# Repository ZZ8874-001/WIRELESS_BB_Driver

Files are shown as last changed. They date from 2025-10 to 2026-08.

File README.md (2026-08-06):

# WireLess BB Driver

同步 Buck 降压变换器固件，STM32F334C8 + 无线模块，非反馈线性控制 (NFB)。

---

## 目录

1. [构建环境](#1-构建环境)
2. [系统架构](#2-系统架构)
3. [外设配置](#3-外设配置)
4. [HRTIM 详细规格](#4-hrtim-详细规格)
5. [控制算法](#5-控制算法)
6. [代码文件结构](#6-代码文件结构)
7. [状态机](#7-状态机)
8. [变量定义与赋值关系](#8-变量定义与赋值关系)
9. [检测系统](#9-检测系统)
10. [ADC 数据流](#10-adc-数据流)
11. [串口通信](#11-串口通信)

---

## 1. 构建环境

```bash
make clean && make -j    # 完整重建
make -j                  # 增量构建
```

| 项 | 值 |
|----|-----|
| MCU | STM32F334C8 |
| 内核 | Cortex-M4 + FPU (fpv4-sp-d16) |
| 编译器 | arm-none-eabi-gcc |
| 优化 | `-O2` |
| 调试 | `-g -gdwarf-2` |
| 输出 | `build/WireLess_BB_Driver.elf/.hex/.bin` |
| 工具链 | STM32CubeMX 生成 HAL + 手动覆盖 |

---

## 2. 系统架构

```
┌────────────────────────────────────────────────────┐
│                    main.c                           │
│  SystemClock_Config() → HSE 8MHz ×6 = 48MHz PLL  │
│  HRTIM1 = PLLCLK (48MHz ×2 = 96MHz)               │
│  APB1 = 24MHz, APB2 = 48MHz                       │
│  ADC12 clock = PLL/2 = 24MHz                      │
│                                                     │
│  HAL_TIM_PeriodElapsedCallback (TIM2 @10kHz)       │
│    ├── Bsp_ADC_ProcessSample()  // 每秒10k次       │
│    ├── Buck_Boost_Task()        // 每秒10k次       │
│    └── Detect_Task()            // 每10tick=1kHz   │
└────────────────────────────────────────────────────┘
```

- **裸机**，无 RTOS
- 所有实时逻辑由 `HAL_TIM_PeriodElapsedCallback` (TIM2) 以 **10 kHz** 驱动
- ADC 由 HRTIM Timer C 在 **~100 kHz** 触发，DMA 循环搬运
- USART3 通过 **DMA + IDLE 中断** 异步接收无线数据

---

## 3. 外设配置

### 3.1 时钟树 (`Core/Src/main.c:143`)

| 时钟 | 来源 | 频率 |
|---|---|---|
| HSE | 外部晶振 | 8 MHz |
| PLL | HSE ×6 | 48 MHz |
| SYSCLK | PLL | 48 MHz |
| HCLK | SYSCLK/1 | 48 MHz |
| APB1 (PCLK1) | HCLK/2 | 24 MHz |
| APB2 (PCLK2) | HCLK/1 | 48 MHz |
| HRTIM1CLK | PLLCLK (×2) | 96 MHz |
| ADC12CLK | PLLCLK/2 | 24 MHz |

### 3.2 GPIO 映射

| 引脚 | 功能 | 方向 | AF | 文件位置 |
|---|---|---|-----|---|
| PA0 | ADC1_IN1 (Vout 采样) | Analog | — | `Core/Src/adc.c:188` |
| PA1 | ADC1_IN2 (Vin 采样) | Analog | — | `Core/Src/adc.c:188` |
| PA4 | ADC2_IN1 (Iout+) | Analog | — | `Core/Src/adc.c:229` |
| PA5 | ADC2_IN2 (Iout-) | Analog | — | `Core/Src/adc.c:229` |
| PA6 | VCC_Indicator | Output PP | — | `Core/Src/gpio.c:56` |
| PA7 | BBEN_Indicator | Output PP | — | `Core/Src/gpio.c:62` |
| PA8 | HRTIM1_CHA1 (ADC触发) | AF PP | AF13 | `Core/Src/hrtim.c:248` |
| PA10 | HRTIM1_CHB1 (Buck 下管) | AF PP | AF13 | `Core/Src/hrtim.c:248` |
| PA11 | HRTIM1_CHB2 (Buck 上管) | AF PP | AF13 | `Core/Src/hrtim.c:248` |
| PB10 | USART3_TX | AF PP | AF7 | `Core/Src/usart.c:80` |
| PB11 | USART3_RX | AF PP | AF7 | `Core/Src/usart.c:80` |

### 3.3 ADC 配置

文件 `Core/Src/adc.c:33` `MX_ADC1_Init()`, `Core/Src/adc.c:117` `MX_ADC2_Init()`

| 参数 | ADC1 | ADC2 |
|---|---|---|
| Clock | Async DIV1 (24 MHz) | Async DIV1 (24 MHz) |
| Resolution | 12 bit | 12 bit |
| Scan | Enabled | Disabled |
| Continuous | Disabled | Disabled |
| Trigger Edge | Rising | Rising |
| **Trigger Src** | `ADC_EXTERNALTRIGCONVHRTIM_TRG1` | `ADC_EXTERNALTRIGCONVHRTIM_TRG3` |
| NbrOfConversion | 2 (CH1=Rank1, CH2=Rank2) | 1 (CH1=Rank1, differential) |
| DMA Requests | Continuous | Continuous |
| Sampling Time | 7.5 cycles | 7.5 cycles |

**DMA 配置** (由 `HAL_ADC_MspInit` 在 `Core/Src/adc.c:171`):

| 参数 | DMA1_Channel1 (ADC1) | DMA1_Channel4 (ADC2) |
|---|---|---|
| Direction | Peripheral → Memory | Peripheral → Memory |
| PeriphInc | Disabled | Disabled |
| MemInc | Enabled | Enabled |
| Data Align | Half-word | Half-word |
| **Mode** | **Circular** | **Circular** |
| Priority | Low | Low |

**BSP 层重配置** (`Bsp/bsp_adc.c:49` `Bsp_ADC_Init()`):

DMA 循环缓冲区长度由头文件定义：
```c
// bsp_adc.h:18-20
#define ADC_VOUT_BUF_SIZE  10
#define ADC_VIN_BUF_SIZE   10
#define ADC_CURR_BUF_SIZE  10

// bsp_adc.h:23-24
#define ADC1_DMA_BUF_SIZE  (ADC_VOUT_BUF_SIZE * 2)  // = 20
#define ADC2_DMA_BUF_SIZE  (ADC_CURR_BUF_SIZE)       // = 10
```

- `ADC1_DMA_Buf[20]`: 交织布局 `[Vout0 ,Vin0 , Vout1, Vin1, ..., Vout9, Vin9]`
- `ADC2_DMA_Buf[10]`: `[I0, I1, ..., I9]`
- DMA 半传输/传输完成中断被**禁用** (`bsp_adc.c:69-70`)
- ADC1 AWD2 模拟看门狗监控 CH2 (Vin) (`bsp_adc.c:73-74`)

### 3.4 USART3 配置

文件 `Core/Src/usart.c:33` `MX_USART3_UART_Init()`

| 参数 | 值 |
|---|-----|
| Baud Rate | 115200 |
| Word Length | 8 bit |
| Stop Bits | 1 |
| Parity | None |
| Mode | TX+RX |
| Hardware Flow | None |
| **OverSampling** | **8×** (`UART_OVERSAMPLING_8`) |
| ISR Priority | 0 (最高) |

**BSP 层重置** (`Bsp/bsp_uart.c:12` `Bsp_UART_Init()`):

直接寄存器写覆盖 HAL 配置：
1. `DMA1_Channel3->CCR = 0` — 清零 RX DMA
2. `USART3->CR1 = 0` — 清零 USART
3. 重新配置 DMA: `CCR |= DMA_CCR_MINC`, CNDTR=255, CPAR=&USART3->RDR, CMAR=Rx_data
4. `USART3->CR3 |= USART_CR3_DMAR | USART_CR3_DMAT` — 启用 DMA 收发
5. `USART3->CR1 |= IDLEIE | TE | RE | UE | OVER8` — **注意**：`OVER8` **必须保留**，否则波特率偏差 2×

**ISR**: `Core/Src/stm32f3xx_it.c:296` `USART3_IRQHandler` → `USER_USART_InterruptCallback(&huart3)` (`Bsp/bsp_uart.c:38`)

### 3.5 TIM2 配置

TIM2 产生 10 kHz 主循环中断。由 CubeMX 生成 `Core/Src/tim.c`。

---

## 4. HRTIM 详细规格

### 4.1 时钟与周期

| 参数 | 值 | 来源 |
|---|-----|---|
| 时钟源 | PLLCLK (96 MHz) | `Core/Src/main.c:179` `RCC_HRTIM1CLK_PLLCLK` |
| Period (Master) | 23040 | `Core/Inc/main.h:63` `Hrtim_Period` |
| 预分频基准 | `HRTIM_PRESCALERRATIO_MUL2` (TimerA) | `Core/Src/hrtim.c:75` |
| DLL 校准 | 14 周期 | `Core/Src/hrtim.c:54` |

### 4.2 Timer 配置

| Timer | 功能 | Prescaler | 周期 (分辨率) | Reset Trigger | Reset Update | 文件位置 |
|---|---|---|---|---|---|---|
| **A**  | 输出 TA1 (ADC 触发基准) | MUL2 | 96M×2/23040 ≈ 8.33 kHz | CMP2 | Enabled | `hrtim.c:73-105` |
| **B**  | Buck PWM (TB1/TB2) | MUL32 | 96M×32/23040 ≈ 133.3 kHz | Update \| Other1_CMP2 | Disabled | `hrtim.c:106-113` |
| **C**  | ADC 触发 | MUL16 | 96M×16/23040 ≈ 66.7 kHz | Other1_CMP2 | Enabled | `hrtim.c:114-121` |

### 4.3 HRTIM 寄存器地址映射

基地址: `HRTIM1 = 0x40017400`

#### Master 寄存器

| 寄存器 | 偏移 | 位宽 | 访问 | 描述 |
|---|---|---|---|---|
| `MCR` | 0x00 | 32 | rw | Master 控制寄存器 |
| `MISR` | 0x04 | 32 | r | Master 中断状态 |
| `MICR` | 0x08 | 32 | w | Master 中断清除 |
| `MDIER` | 0x0C | 32 | rw | Master DMA/中断使能 |
| `MCNTR` | 0x10 | 32 | r | Master 计数器 (只读) |
| `MPER` | 0x14 | 32 | rw | Master 周期 |
| `MREP` | 0x18 | 32 | rw | Master 重复计数 |
| `MCMP1R` | 0x1C | 32 | rw | Master 比较 1 |
| `MCMP2R` | 0x24 | 32 | rw | Master 比较 2 |
| `MCMP3R` | 0x28 | 32 | rw | Master 比较 3 |
| `MCMP4R` | 0x2C | 32 | rw | Master 比较 4 |

#### Timer A 寄存器 (sTimerxRegs[0], 偏移 0x80)

| 寄存器 | 偏移 | 描述 |
|---|---|---|
| `TIMxCR` | 0x80 | Timer A 控制 |
| `TIMxISR` | 0x84 | Timer A 中断状态 |
| `TIMxICR` | 0x88 | Timer A 中断清除 |
| `TIMxDIER` | 0x8C | Timer A DMA/中断使能 |
| `CNTxR` | 0x90 | Timer A 计数器 |
| `PERxR` | 0x94 | Timer A 周期 |
| `REPxR` | 0x98 | Timer A 重复 |
| `CMP1xR` | 0x9C | Timer A 比较 1 |
| `CMP2xR` | 0xA4 | Timer A 比较 2 |
| `CMP3xR` | 0xA8 | Timer A 比较 3 |
| `CMP4xR` | 0xAC | Timer A 比较 4 |

#### Timer B 寄存器 (sTimerxRegs[1], 偏移 0x100)

| 寄存器 | 偏移 | 描述 |
|---|---|---|
| `CMP1xR` | 0x11C | Timer B 比较 1 (Buck 下管) |
| `CMP2xR` | 0x124 | Timer B 比较 2 (Buck 上管) |

#### Timer C 寄存器 (sTimerxRegs[2], 偏移 0x180)

| 寄存器 | 偏移 | 描述 |
|---|---|---|
| `CMP2xR` | 0x1A4 | Timer C 比较 2 → ADC Trigger 1 |
| `CMP3xR` | 0x1A8 | Timer C 比较 3 → ADC Trigger 3 |

#### 公共控制寄存器

| 寄存器 | 偏移 | 访问 | 描述 |
|---|---|---|---|
| `OENR` | 0x380 | w | 输出使能 Set (`bb_control.c:108,387`) |
| `ODISR` | 0x384 | w | 输出禁能 Set (`bb_control.c:109,391`) |

### 4.4 比较值与触发配置

| 比较器 | 值 | 用途 | 文件 |
|---|-----|---|---|
| Timer A CMP2 | `Hrtim_Period` (=23040) | Timer A 自复位 + Timer B/C 复位基准 | `hrtim.c:122` |
| Timer A CMP3 | `Hrtim_Period/32` (=720) | TA1 输出 Set | `hrtim.c:137` |
| Timer A CMP4 | `Hrtim_Period/32+96` (=816) | TA1 输出 Reset | `hrtim.c:143` |
| Timer B CMP1 | `(Period-Period/2)/2*0.95` | TB1 输出 Set (下管) | `hrtim.c:176` |
| Timer B CMP2 | `(Period+Period/2)/2*0.95` | TB1 输出 Reset / TB2 Set (上管,运行时改写) | `hrtim.c:130` |
| Timer C CMP2 | `Hrtim_Period/4` (=5760) | ADC Trigger 1 | `hrtim.c:133` |
| Timer C CMP3 | `Hrtim_Period/4+96` (=5856) | ADC Trigger 3 | `hrtim.c:204` |

### 4.5 输出配置

| 输出 | 编号 | Set Src | Reset Src | Idle | 实际使用 |
|---|---|---|---|---|---|
| TA1 | 0 | TIMCMP3 | TIMCMP4 | Inactive | ADC 触发基准 |
| TB1 | 1 | TIMCMP1 | TIMCMP2 | Inactive | Buck 下管 (同步整流) |
| TB2 | 2 | NONE | NONE | Inactive | Buck 上管 (互补, 由死区生成) |

死区时间 (`hrtim.c:181-193`):
- 上升沿 (Rising): +10 (Prescaler DIV1)
- 下降沿 (Falling): +10

### 4.6 ADC 触发连接

| ADC 通道 | HRTIM 触发 | 源事件 | 更新源 | 文件 |
|---|---|---|---|---|
| ADC1 | `HRTIM_ADCTRIGGER_1` | `TIMERC_CMP2` | `UPDATE_TIMER_C` | `hrtim.c:62-66` |
| ADC2 | `HRTIM_ADCTRIGGER_3` | `TIMERC_CMP3` | `UPDATE_TIMER_C` | `hrtim.c:68-71` |

### 4.7 代码中对 HRTIM 寄存器的直接写入

| 操作 | 位置 | 说明 |
|---|---|---|
| `sCommonRegs.OENR = BUCK_OUTPUT_MASK` | `bb_control.c:387` | 使能 TB1/TB2 输出 |
| `sCommonRegs.ODISR = BUCK_OUTPUT_MASK` | `bb_control.c:391` | 禁能 TB1/TB2 输出 |
| `sCommonRegs.OENR = HRTIM_OUTPUT_TA1` | `bb_control.c:108` | 使能 TA1 (ADC 触发) |
| `sCommonRegs.ODISR = BUCK_OUTPUT_MASK` | `bb_control.c:109` | 禁能 TB1/TB2 (初始化) |
| `sMasterRegs.MCMP1R = Hrtim_Period` | `main.c:110` | Master 比较 1 |
| `sMasterRegs.MCMP2R = 0` | `main.c:111` | Master 比较 2 |
| `sTimerxRegs[B].CMP1xR = ...` | `bb_control.c:357,362` | Buck 下管关断点 |
| `sTimerxRegs[B].CMP2xR = ...` | `bb_control.c:358,363` | Buck 上管关断点 |
| `sTimerxRegs[B].CMP1xR = Hrtim_Period` | `bb_control.c:357` | 故障态: 下管永开 |
| `sTimerxRegs[B].CMP2xR = 0` | `bb_control.c:358` | 故障态: 上管永关 |

### 4.8 HRTIM 输出掩码位定义

```c
// stm32f3xx_hal_hrtim.h
HRTIM_OUTPUT_TA1 = (0x00000002U)  // bit 1
HRTIM_OUTPUT_TB1 = (0x00000008U)  // bit 3
HRTIM_OUTPUT_TB2 = (0x00000010U)  // bit 4
BUCK_OUTPUT_MASK  = HRTIM_OUTPUT_TB1 | HRTIM_OUTPUT_TB2  // = 0x18
```

---

## 5. 控制算法

### 5.1 NFB (Non-Linear Feedback) 非反馈控制

`bb_control.c:367` `NFB_Calculate()` (10 kHz 调用):

```
① 电压增益计算
  voltage_gain_measure_ = constrain(Vout/Vin, 0.05, 0.95)   // 实测增益
  voltage_gain_ref_     = constrain(Vref/Vin,  0.05, 0.95)   // 目标增益

② Gain_Limit = max(0.95 - gain_ref, gain_ref - 0.05)

③ 电压环
  err_volt = (gain_measure - gain_ref) / Gain_Limit
  voltage_gain_NFB_ = gain_ref + Kp_Volt × sin(err_volt × π/2)
  约束到 [0.05, 0.95]

④ 电流环
  Curr_Normalized = constrain((Iout - Iref) / Iref, -0.95, 0.95)
  current_gain_NFB_ = volt_gain_NFB + Kp_Curr × sin(Curr_Normalized × π/2)
  约束到 [0.05, 0.95]

⑤ 电流增益滤波
  current_gain_NFB_f_ = First_Order_Filter(current_gain_NFB_)  // fc=50Hz
```

### 5.2 CV/CC 切换

`bb_control.c:273` 在 `Data_Handle()` 中:

```
if Iout > Iref + 0.05  →  is_CC = 1  →  Kp_Curr_NFB ×1.001  (逐步收紧)
if Iout < Iref         →  is_CC = 0  →  Kp_Curr_NFB ×0.95   (逐步放松)

final_gain = 
  if cur_gain_f > volt_gain × 1.05 && 超时过期 → volt_gain (电压环占优)
  if cur_gain_f < volt_gain                    → cur_gain_f (电流环占优, 且钩住 TOE)
  else                                         → (volt_gain + cur_gain_f) / 2 (平滑过渡)
```

### 5.3 占空比计算

`bb_control.c:316` `Duty_Calculate()`:

| 状态 | 占空比 |
|---|---|
| Buck | `constrain(final_gain, 0.05, 0.95)` |
| VoltIpt_Error | `0` |
| Soft_Start | `constrain(final_gain × (t - t0)/200ms + 0.026, 0.05, 0.95)` |

### 5.4 PWM 输出

`bb_control.c:343` `MOS_PWM_Set()` — 直接写 HRTIM Timer B 的比较寄存器:

- 上管 (TB2): `CMP2xR = (1 + (1-duty)) / 2 × Hrtim_Period`
- 下管 (TB1): `CMP1xR = (1 - (1-duty)) / 2 × Hrtim_Period`
- 故障态: 上管 CMP2=0 (永关), 下管 CMP1=Period (永开)

### 5.5 灌电流/过压保护 (OVP)

`bb_control.c:395` `Is_Buck_OutputVoltage_Allowed()`:

```
滞回比较器:
  触发: Vout > Vin × 1.40  →  active = true  →  输出禁止
  释放: Vout ≤ Vin × 0.85  →  active = false →  输出使能
```

`bb_control.c:383` `Update_Buck_Output_Enable()`:
- `Wireless_EN_flag && OVP 允许` → `OENR = BUCK_OUTPUT_MASK`
- 否则 → `ODISR = BUCK_OUTPUT_MASK`

---

## 6. 代码文件结构

```
BB_Driver/
├── Core/                          # CubeMX 生成
│   ├── Inc/
│   │   ├── main.h                 # 全局宏: 占空比限幅, Pin 定义
│   │   ├── adc.h / dma.h / gpio.h / hrtim.h / tim.h / usart.h
│   │   └── stm32f3xx_it.h
│   └── Src/
│       ├── main.c                 # 入口, 时钟, TIM2 回调
│       ├── adc.c                  # MX_ADC1/2_Init, HAL_ADC_MspInit
│       ├── dma.c                  # MX_DMA_Init
│       ├── gpio.c                 # MX_GPIO_Init (指示灯)
│       ├── hrtim.c                # MX_HRTIM1_Init (Timer A/B/C, ADC Trigger, 输出)
│       ├── tim.c / usart.c        # CubeMX 外设生成
│       ├── stm32f3xx_it.c         # USART3/DMA 中断向量
│       └── system_stm32f3xx.c
│
├── Application/                   # 应用层
│   ├── bb_control.c               # 核心: 状态机 + NFB + PWM + OVP
│   ├── bb_control.h               # Buck_Boost_Str 结构体, 常量, 状态枚举
│   ├── detect_task.c              # 7 路超时检测看门狗
│   ├── detect_task.h              # TOE 枚举, Detect_t 结构体
│   ├── board_id.c                 # STM32 UID → 板号 (5 块板)
│   └── board_id.h                 # BOARD_NUM=5, BoardID_t 结构体
│
├── Bsp/                           # 板级支持
│   ├── bsp_adc.c                  # DMA 循环缓冲 + 整型滤波 + 看门狗
│   ├── bsp_adc.h                  # 缓冲大小宏, 函数声明
│   ├── bsp_uart.c                 # DMA+IDLE 直接寄存器重配
│   ├── bsp_uart.h                 # USART_Rx_Buf_t 结构体
│   ├── bsp_dwt.c                  # DWT 微秒延时
│   └── bsp_dwt.h
│
├── Commponents/                   # 通用算法库
│   ├── filter32.c/h               # 一阶低通 (浮点+定点), 窗口, IIR
│   ├── user_lib.c/h               # 限幅/死区/OLS/斜坡等数学工具
│   ├── Controller/controller.c/h  # PID/模糊PID/前馈/LDOB/微分跟踪器
│   └── Include/arm_math.h
│
├── Drivers/                       # STM32 HAL + CMSIS
├── WireLess_BB_Driver.ioc         # CubeMX 工程
└── Makefile
```

---

## 7. 状态机

`bb_control.c:153` `Choose_State()`

```
                  ┌─────────────┐
         init ──→ │ VoltIpt_    │
                  │  Error      │
                  └──┬──────┬───┘
           Vin正常   │      │ 条件不满足
           +Wireless │      │
           +OVP允许  │      │
                  ┌──▼──────▼───┐   200ms后   ┌──────┐
                  │  Soft_Start │ ──────────→ │ Buck │
                  └──┬──────────┘             └──┬───┘
           条件消失  │                   条件消失 │ (Vin超限或
           (任意)   │                  +Vin<BUCK_│  Wireless断)
                    │                   HIGH     │
                    └────→ VoltIpt_Error ←───────┘
```

**None** 状态为过渡态，直接跳转 VoltIpt_Error。**Boost** 和 **Buck_Boost** 留空未使用。

---

## 8. 变量定义与赋值关系

### 8.1 全局结构体 `Buck_Boost_Str bb` (`bb_control.c:74`)

| 字段 | 类型 | 初始值 | 写入位置 |
|---|---|---|---|
| `voltage_out_f_` | float | 0 | `bsp_adc.c:123` (滤波后 Vout) |
| `voltage_in_f_` | float | 0 | `bsp_adc.c:125` (滤波后 Vin) |
| `current_out_f_` | float | 0 | `bsp_adc.c:137` (滤波后 Iout) |
| `voltage_gain_measure_` | float | 0 | `bb_control.c:269` (Vout/Vin) |
| `voltage_gain_ref_` | float | 0 | `bb_control.c:270` (Vref/Vin) |
| `voltage_out_ref_` | float | VOLTAGE_OUT_REF (26.4f) | `bb_control.c:89` (Init) |
| `current_out_ref_` | float | CURRENT_OUT_MAX (5.1f) | `bb_control.c:88` (Init) |
| `buck_duty_cycle_` | float | 0 | `bb_control.c:324/328/334` |
| `voltage_gain_NFB_` | float | 0 | `bb_control.c:373` (电压环输出) |
| `current_gain_NFB_` | float | 0 | `bb_control.c:377` (电流环输出) |
| `current_gain_NFB_f_` | float | 0 | `bb_control.c:379` (电流增益滤波) |
| `voltage_out_filter_` | First_Order_Filter_t | Init | `bsp_adc.c:48` — **本分支未使用** |
| `voltage_in_filter_` | First_Order_Filter_t | Init | `bsp_adc.c:48` — **本分支未使用** |
| `current_out_filter_` | First_Order_Filter_t | Init | `bsp_adc.c:48` — **本分支未使用** |
| `current_gain_NFB_filter_` | First_Order_Filter_t | fc=50Hz | `bb_control.c:98` (Init) |

### 8.2 状态变量

| 变量 | 类型 | 作用域 | 初始值 | 写入位置 |
|---|---|---|---|---|
| `bb_state` | enum | 全局 | VoltIpt_Error | `bb_control.c:184,191,216,243,256` |
| `last_bb_state` | enum | 文件 static | VoltIpt_Error | `bb_control.c:175,183,190,215,242,250,255` |
| `Wireless_EN_flag` | bool | 文件 static | false | `bb_control.c:120,124,128` |
| `Wireless_data` | bool | 文件 static | false | `bb_control.c:414` (WirelessRx_DataHandle) |
| `Buck_output_ovp_active` | bool | 文件 static | false | `bb_control.c:401,406` |
| `is_CC` | bool | 文件 static | 0 | `bb_control.c:275,281` |
| `Kp_Curr_NFB` | float | 文件 static | -0.4f | `bb_control.c:276,282` |
| `enter_soft_start_time` | float | 文件 static | 0 | `bb_control.c:251` |
| `voltage_gain_final_output` | float | 文件 static | 0 | `bb_control.c:313` |

### 8.3 ADC 滤波状态变量 (`bsp_adc.c`)

| 变量 | 类型 | 初始值 | 写入位置 |
|---|---|---|---|
| `adc_filter_vout` | Int_FirstOrderFilter_t | Init | `bsp_adc.c:Init+Calculate` |
| `adc_filter_vin` | Int_FirstOrderFilter_t | Init | `bsp_adc.c:Init+Calculate` |
| `adc_filter_curr` | Int_FirstOrderFilter_t | Init | `bsp_adc.c:Init+Calculate` |
| `adc_filter_inited` | uint8_t | 0 | `bsp_adc.c:ProcessSample` |

### 8.4 关键常量

| 常量 | 值 | 文件 |
|---|-----|---|
| `VOLTAGE_OUT_REF` | 26.4f | `bb_control.h:10` |
| `CURRENT_OUT_MAX` | 5.1f | `bb_control.h:11` |
| `VOLTAGE_IN_MAX` | 100.0f | `bb_control.h:12` |
| `VOLTAGE_IN_MIN` | 0.0f | `bb_control.h:13` |
| `BUCK_HIGH` | 52.0f | `bb_control.c:49` |
| `SS_2_BUCK_TIME` | 200 ms | `bb_control.c:51` |
| `BUCK_OUTPUT_OVERVOLT_DISABLE_RATIO` | 1.40f | `bb_control.c:53` |
| `BUCK_OUTPUT_OVERVOLT_RELEASE_RATIO` | 0.85f | `bb_control.c:54` |
| `Hrtim_Period` | 23040 | `main.h:63` |
| `L_duty` | 0.05f | `main.h:60` |
| `H_duty` | 0.95f | `main.h:62` |
| `deadtime` | 100 | `main.h:61` |

---

## 9. 检测系统

### 9.1 TOE 枚举 (`detect_task.h:26`)

| 序号 | 名称 | 超时 (ms) | Hook 位置 | Check 位置 |
|---|---|---|---|---|
| 0 | `ADC1_WATCHDOG1_TOE` | 1000 | `bsp_adc.c:149` | `bb_control.c:139` |
| 1 | `ADC1_WATCHDOG2_TOE` | 1000 | `bsp_adc.c:161` | `bb_control.c:140` |
| 2 | `ADC2_WATCHDOG1_TOE` | 1000 | `bsp_adc.c:153` | — |
| 3 | `VoltIpt_Error_TOE` | 10 | `bb_control.c:186,194,202,245` | `bb_control.c:353` |
| 4 | `CURRENT_TO_VOLTAGE_TOE` | 10 (宏) | `bb_control.c:296` | `bb_control.c:288` |
| 5 | `USART3_BUCKEN_TOE` | 25 | `bsp_uart.c:48` | `bb_control.c:118,162,225` |
| 6 | `SINK_CURRENT_PROTECT_TOE` | 1 | (待实现) | (待实现) |

### 9.2 检测 API

| 函数 | 位置 | 功能 |
|---|---|---|
| `Detect_Init()` | `detect_task.c:6` | 初始化 7 路 TOE，设置 ms 阈值 |
| `Detect_Task()` | `detect_task.c:27` | 1 kHz 巡检，逐路计算 dt_ms |
| `Detect_Hook(toe)` | `detect_task.c:55` | 重置指定 TOE 的时间戳 |
| `is_TOE_Overtime(toe)` | `detect_task.c:61` | 返回 1=已超时, 0=未超时 |

---

## 10. ADC 数据流

```
HRTIM Timer C CMP2 ──→ ADC1 Trigger ──→ 2ch Scan ──→ DMA1_Ch1 Circular
  (~66.7kHz)            AWD 监控 CH2       CH1: Vout    → ADC1_DMA_Buf[20]
                                            CH2: Vin       [V0,Vi0, V1,Vi1,...]

HRTIM Timer C CMP3 ──→ ADC2 Trigger ──→ 1ch ──→ DMA1_Ch4 Circular
                                            CH1: Iout    → ADC2_DMA_Buf[10]
                                            (Differential) [I0, I1, ... I9]

TIM2 @10kHz:
  Bsp_ADC_ProcessSample()               // bsp_adc.c:93
    ├── Int_FirstOrderFilter_Calculate ×10  (Vout raw)
    ├── Int_FirstOrderFilter_Calculate ×10  (Vin raw)
    ├── Int_FirstOrderFilter_Calculate ×10  (Curr raw)
    ├── bb.voltage_out_f_ = state_vout × Ratio + Offset  // 一次浮点转换
    ├── bb.voltage_in_f_  = state_vin  × Ratio + Offset
    └── bb.current_out_f_ = (2048 - state_curr) × Ratio + Offset
```

---

## 11. 串口通信

### 11.1 接收流程

```
无线模块 ──uart──→ PB11 (USART3_RX)
                      │
          DMA1_Ch3 Circular? No, Normal mode (CNDTR=255)
          → Rx_data[255]
                      │
          IDLE 检测 (1 字节间隙 = ~87µs)
          → USART3_IRQHandler → USER_USART_InterruptCallback
                      │
          ├── WirelessRx_DataHandle(Rx_data)
          │     search 0xAA in first 2 bytes → Wireless_data
          ├── Detect_Hook(USART3_BUCKEN_TOE)  (25ms 看门狗重置)
          └── DMA 重置: CNDTR=255, 重新使能
```

### 11.2 协议

- 有效帧头: `0xAA` (字节0 或 字节1 含 0xAA)
- 超时阈值: 25 ms (25 次 1kHz 巡检未收到 IDLE)
- 超时 → `Wireless_EN_flag = false` → 状态机回 VoltIpt_Error → PWM 禁能

---

## 附录: 主要函数索引

| 函数 | 文件:行 | 调用频率 |
|---|---|---|
| `main()` | `Core/Src/main.c:74` | 一次 |
| `SystemClock_Config()` | `Core/Src/main.c:143` | 一次 |
| `HAL_TIM_PeriodElapsedCallback()` | `Core/Src/main.c:198` | 10 kHz (TIM2) |
| `Bsp_ADC_Init()` | `Bsp/bsp_adc.c:49` | 一次 |
| `Bsp_ADC_ProcessSample()` | `Bsp/bsp_adc.c:93` | 10 kHz |
| `Buck_Boost_Task()` | `Application/bb_control.c:116` | 10 kHz |
| `Choose_State()` | `Application/bb_control.c:153` | 10 kHz |
| `Data_Handle()` | `Application/bb_control.c:264` | 10 kHz |
| `NFB_Calculate()` | `Application/bb_control.c:367` | 10 kHz |
| `Duty_Calculate()` | `Application/bb_control.c:316` | 10 kHz |
| `MOS_PWM_Set()` | `Application/bb_control.c:343` | 10 kHz |
| `Update_Buck_Output_Enable()` | `Application/bb_control.c:383` | 10 kHz |
| `Is_Buck_OutputVoltage_Allowed()` | `Application/bb_control.c:395` | 10 kHz |
| `Detect_Task()` | `Application/detect_task.c:27` | 1 kHz |
| `Detect_Hook()` | `Application/detect_task.c:55` | 事件驱动 |
| `HAL_ADC_ConvCpltCallback()` | `Bsp/bsp_adc.c:139` | ~66.7 kHz (空函数) |
| `Bsp_UART_Init()` | `Bsp/bsp_uart.c:12` | 一次 |
| `USER_USART_InterruptCallback()` | `Bsp/bsp_uart.c:38` | IDLE 事件 |
| `WirelessRx_DataHandle()` | `Application/bb_control.c:412` | IDLE 事件 |
| `BoardID_Detect()` | `Application/board_id.c:55` | 一次 |
| `Int_FirstOrderFilter_Init()` | `Commponents/filter32.c:175` | 一次/每 filter |
| `Int_FirstOrderFilter_Calculate()` | `Commponents/filter32.c:199` | 10 kHz × 30 |

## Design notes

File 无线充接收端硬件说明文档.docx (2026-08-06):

# 哈工程创梦之翼战队

# 无线充电装置硬件说明（移动端）

版本：1.0.1

26创梦之翼硬件组

## 抽象

该模块是一款双微MCU架构（双STM32F334C8T6）的第二代无线充电（WLC）控制系统 。目前，该系统可以实现稳定的受电线圈检测，带内功率收发通信功能。截止文档编写，未见其他战队类似开源项目实现双机带内通信功能。

电源驱动与采样部分：系统采用 24V 在线输入 ，非输电状态通过超级电容管理模块提供运行必须的电流。功率核心由程序控制的 CSD19534高性能 MOSFET 组成的桥式拓扑构成，实现持续输出超过5A的大功率Buck变换 ；配合 SGM48524 驱动器 激励功率线圈（COIL） 实现与功率发射端的带内无线通信。为确保闭环控制精度，电路集成了 INA240A1 高精度电流采样放大器 与基于 TL431 的电压基准电路 ，实现对电压、电流的实时高精度检测 。

通信驱动与逻辑控制部分：系统由两颗 MCU 协同管理，通过内部 USART 串口进行双机通信 ：正面的MCU负责驱动Buck电路，背面的MCU驱动通信电路并和车上其他模块的通信。对外通信方面，集成了 TJA1044 CAN 总线收发器 ，支持高可靠性的远程数据交换。每颗 MCU 均配备独立的 SWD 调试端口 及由 LED 组成的系统状态指示。

## 硬件系统概览

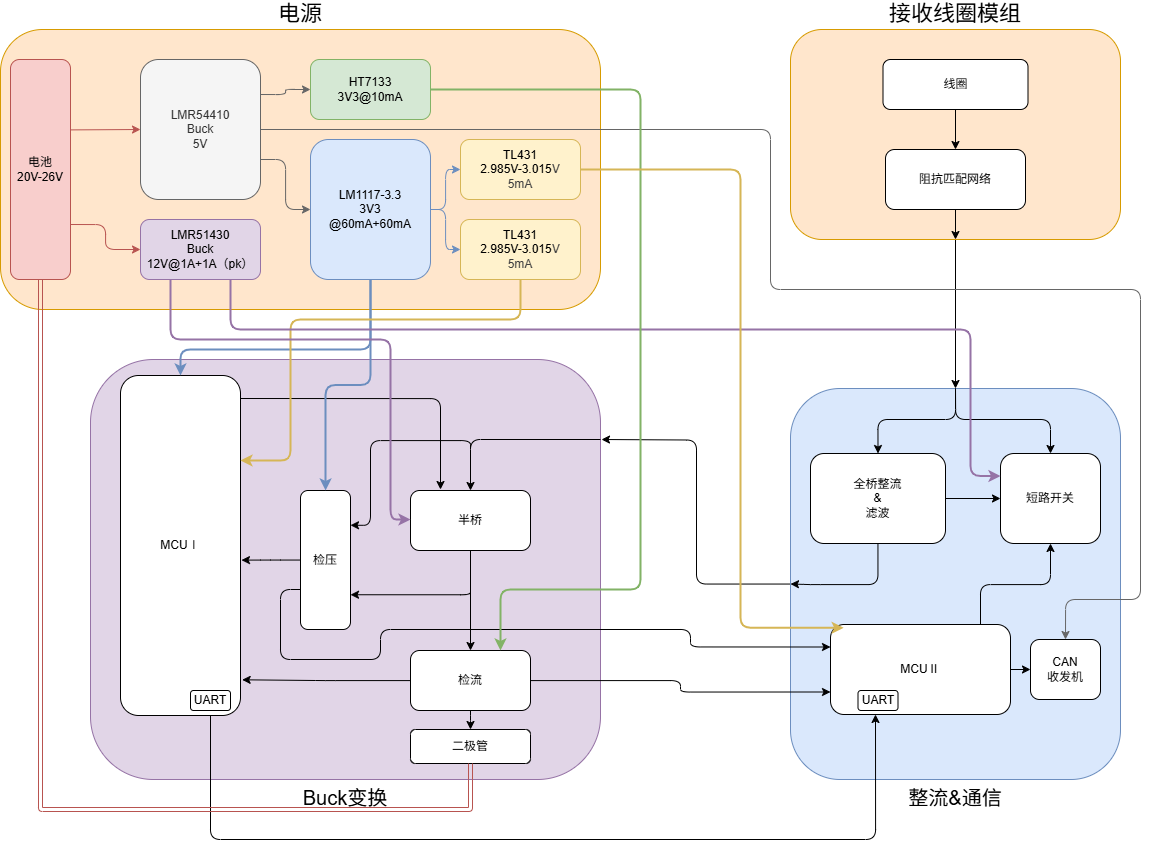
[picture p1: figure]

图：硬件系统主要结构图

1. 电源模块

该模块负责将外部电池输入的直流电转换为系统所需的各级电压：

- 主输入：接收 20V-26V 的电池电压。
- 多级降压：利用 LMR54410 产生 5V 电压，控制部分供电；同时通过 LMR51430 提供 12V@1A 的动力电源，栅极驱动供电。
- 线性稳压与基准：采用 HT7133 和 LM1117-3.3 分别输出 3.3V 逻辑电压；此外，利用 TL431 产生精密的电压基准（约 3V），为采样电路提供参考。

2. Buck 变换模块

该模块是系统的功率核心，主要由 MCU I (U3) 进行闭环控制（目前只有电流环和电压环）：

- 功率拓扑：常见的半桥Buck拓扑结构，MCU发送信号给UCC27211Q1驱动器，驱动两颗CSD19534Mos交替导通。上下管极限上升时间为40ns，死区保守设置在60ns。极限最大占空比0.95，最小0.05。
- 采样检测：集成了由 INA240A1 构成的高精度检流电路 及电压检测电路（检压），实时将功率状态反馈给 MCU I。
- 储能元件：电路中配置了 15uH 大电流电感用于功率滤波与变换 。
- 通信接口：集成 TJA1044 收发器以支持 CAN 总线远程通信，并预留 UART 接口实现两颗 MCU 之间或与外部设备的数据交换。预留外接UART（可配成IIC但无外部上拉）。

3. 整流与通信模块

该模块负责无线信号的接收处理及外部数据交互，由 MCU II (U11) 独立管理：

- 能量接收与整流：无线线圈信号通过阻抗匹配网络后，由全桥整流与滤波电路转换为直流。直流电压安全范围为14-52V，超过52V需要buck半桥主动导通泄放。如果在整流后电压超过88V的情况下强制开启Buck上管，可能导致栅极驱动器永久击穿。
- 开关控制：使用 SGM48524 低侧驱动器配合 CSD18540 MOSFET 实现短路开关功能，实现收->发通信。
- 通信接口：集成 TJA1044 收发器以支持 CAN 总线远程通信，并预留 UART 接口实现两颗 MCU 之间或与外部设备的数据交换。预留外接UART（可配成IIC但无外部上拉）。

## 电气特性

### 绝对额定最大值

名称 | 符号 | 最大 | 最小 | 备注
电池侧输入电压 | V_(BTT) | 36V | 14V | 瞬间过压51430输出短路
空载线圈侧输入峰值 | V_(Coil) | 88V | - | 有被动泄放，建议主动泄放
空载发射相位差 | φ_(Flt) | 48° | - | 对应发射端全桥逆变相位差
Buck变换输出电流 | I_o | 8.1A | - | 测试条件为直流

### 推荐工作条件

名称 | 符号 | 最大 | 标称 | 最小 | 备注
电池侧输入电压 | V_(BTT) | 26V | 24V | 20V | 标定输出电压24V
空载线圈侧输入峰值 | V_(Coil) | 48V | 38V | 33V | 33V为有效通信最小值
空载发射相位差 | φ_(Flt) | 45° | 34° | 30° | 30°为接收检测边缘
Buck变换输出电流 | I_o | 5.2A | 5.0A | - | 充电功率最大120W
Buck电压增益 | V_(gain) | 0.95 | - | 0.05 | 软件限制最小0.5
Buck半桥死区 整流管压降 | T_d V_d | 400ns 0.35 | 60ns 0.30 | 30ns 0.25 | V_g 极限上升时间约20ns -
热参数（持续） | t_b | 63.79 | 48.80 | - | 整流管热严重，其他热较平均

## 布局

### 接口布局

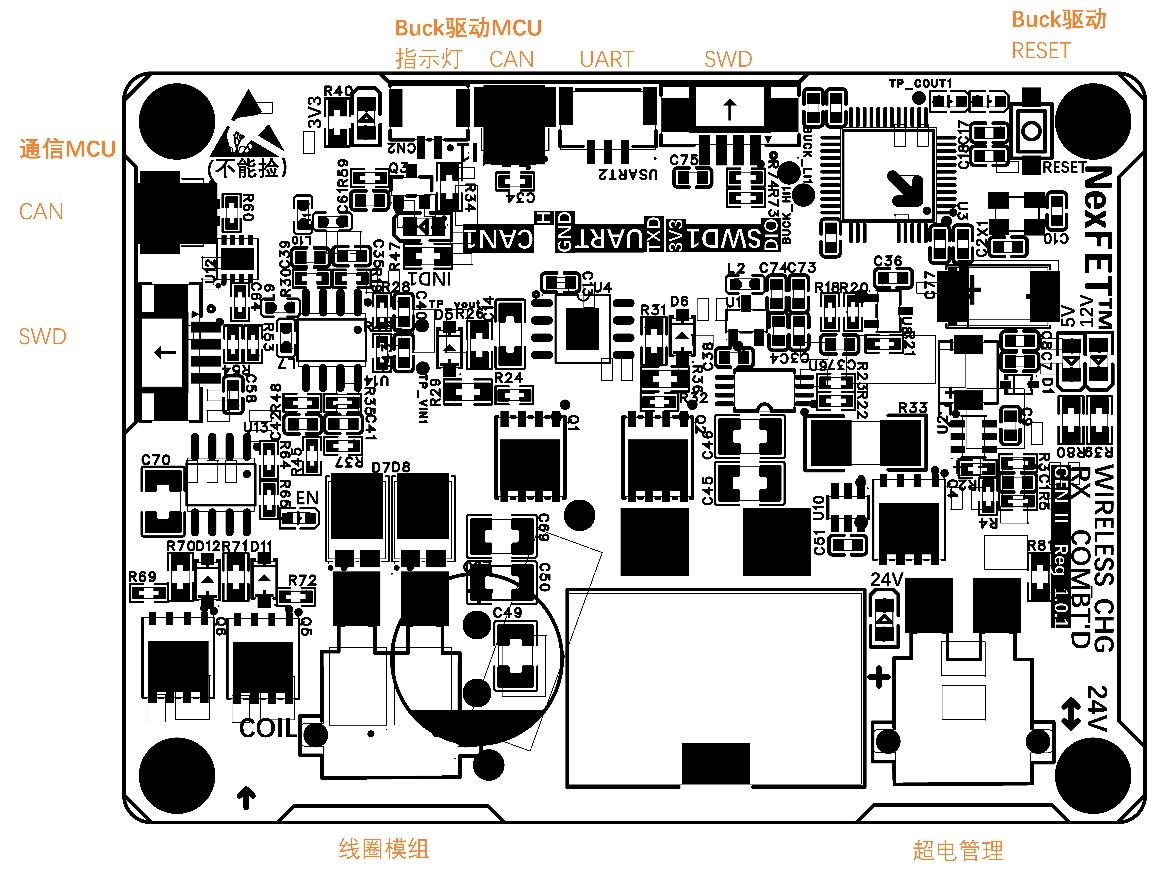
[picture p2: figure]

### 模块布局

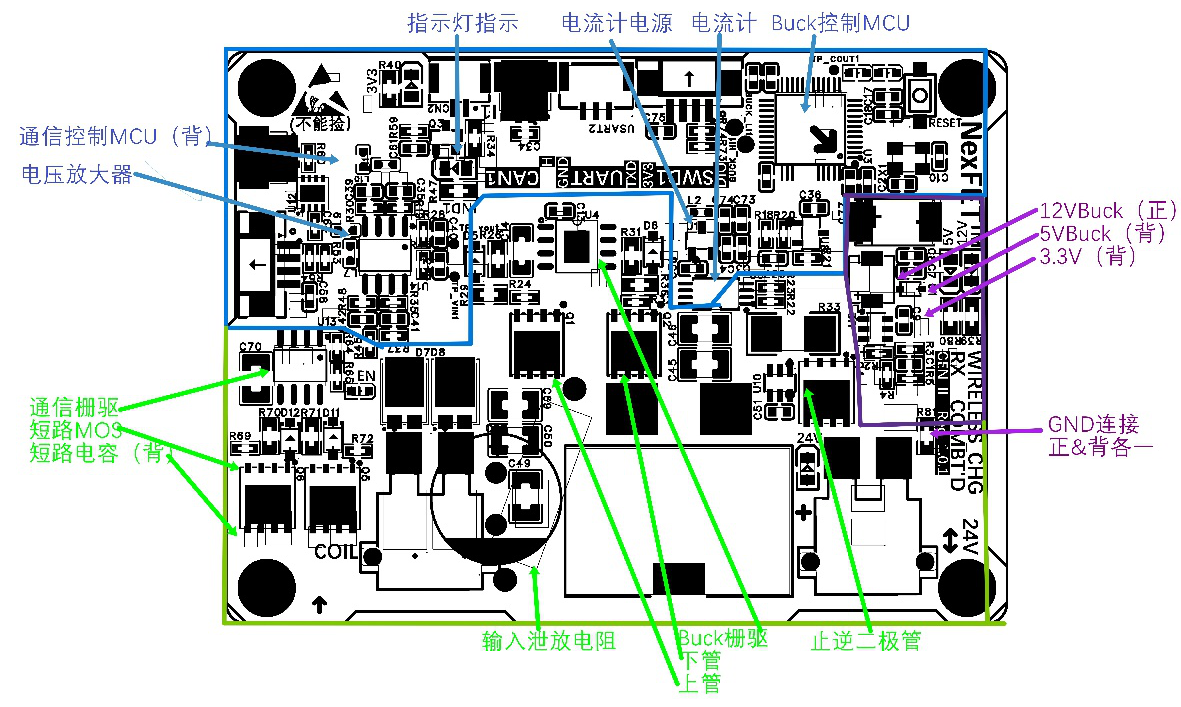
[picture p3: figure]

## 原理图

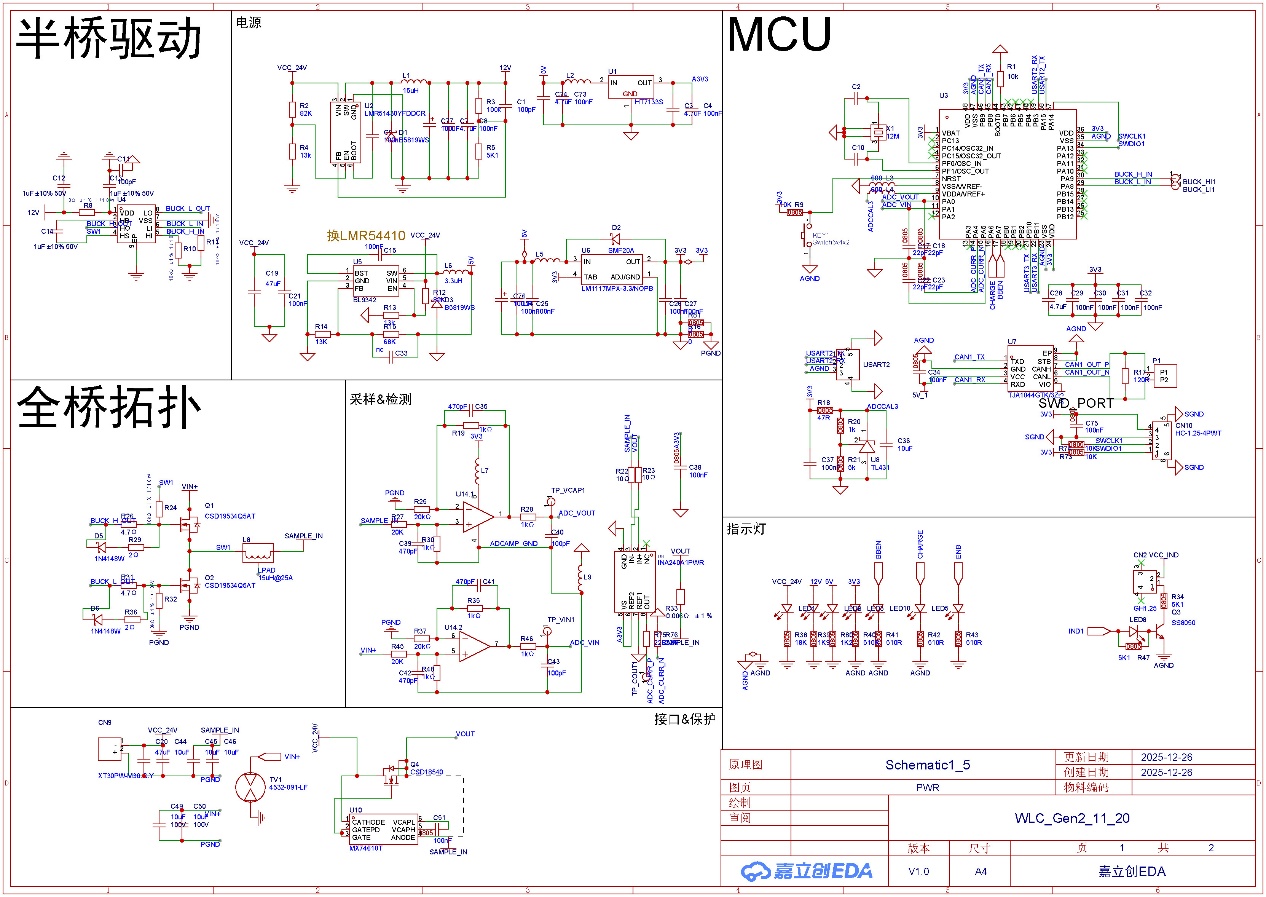
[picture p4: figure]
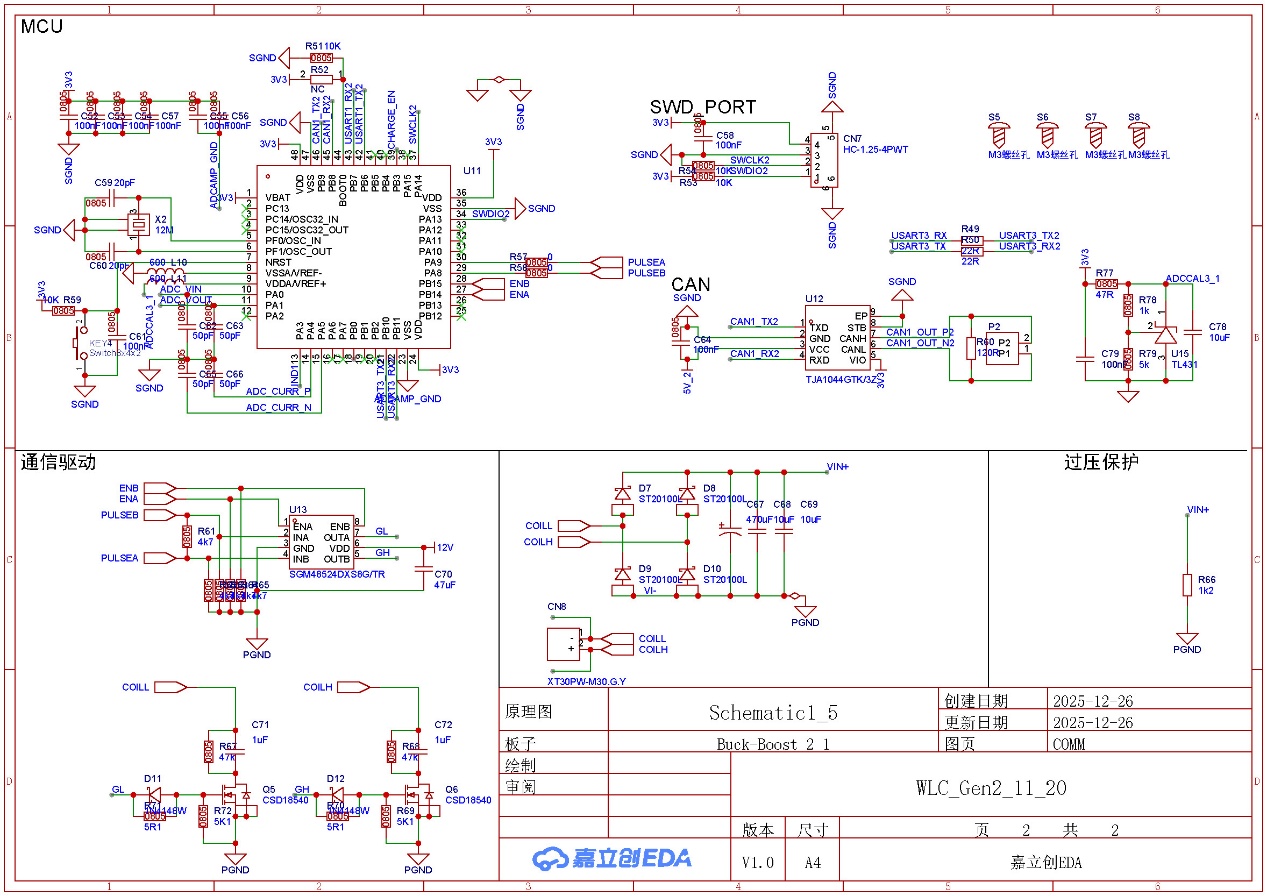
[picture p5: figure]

## 尺寸

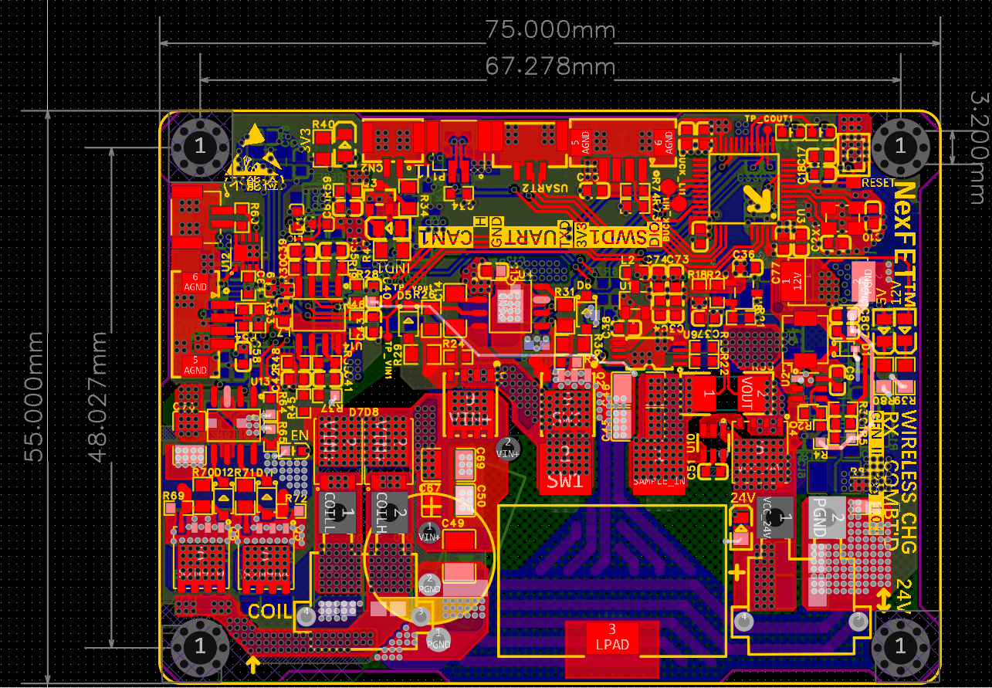
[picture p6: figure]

## 修订记录

更改 | 日期 | 内容 | 文档版本 | PCB版本
1 | 2026年1月21日 | 首次提交 | 1.0.1 | 1.0.1

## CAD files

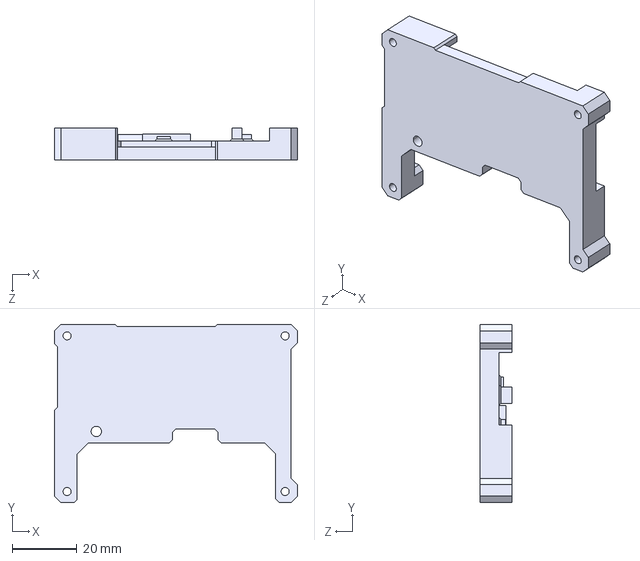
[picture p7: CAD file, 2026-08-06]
3Ds/接收端散热-光.STEP
75.0 x 55.0 x 10.0 mm

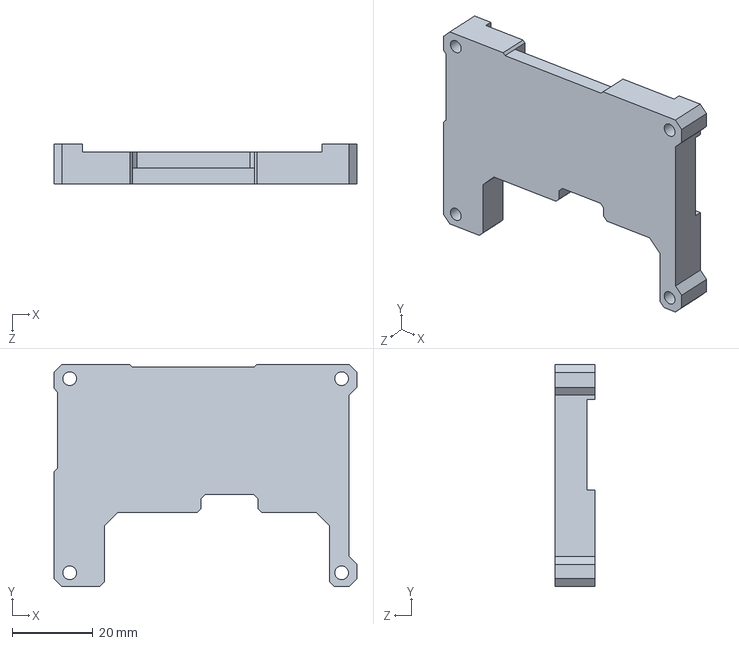
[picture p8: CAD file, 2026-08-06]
3Ds/接收端散热-光-b.SLDPRT
75.0 x 55.0 x 10.0 mm

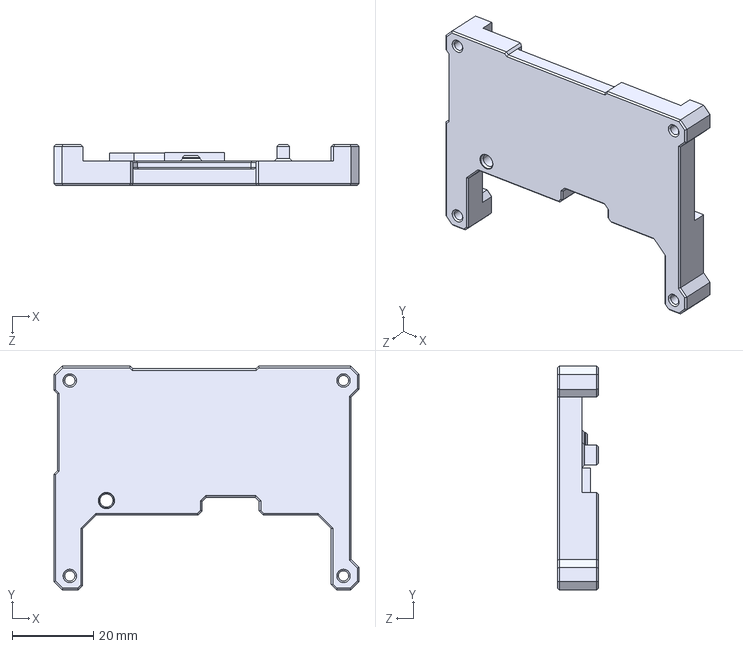
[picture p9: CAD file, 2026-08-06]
3Ds/接收端散热-光-2.STEP
75.0 x 55.0 x 10.0 mm

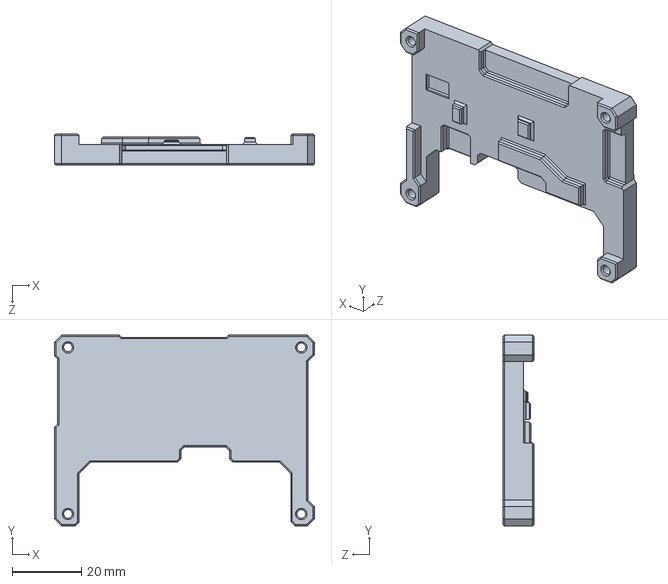
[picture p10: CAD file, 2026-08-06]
3Ds/备份 属于 接收端散热-光-2-Al.SLDPRT
75.0 x 55.0 x 9.00 mm

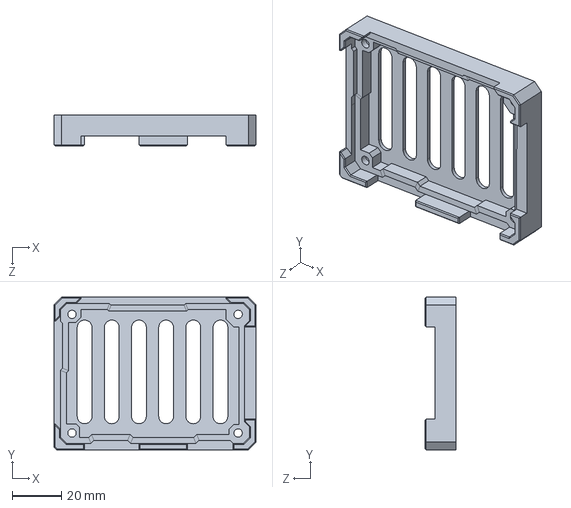
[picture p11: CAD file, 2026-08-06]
3Ds/备份 属于 接收端底板.SLDPRT
81.8 x 61.8 x 12.4 mm

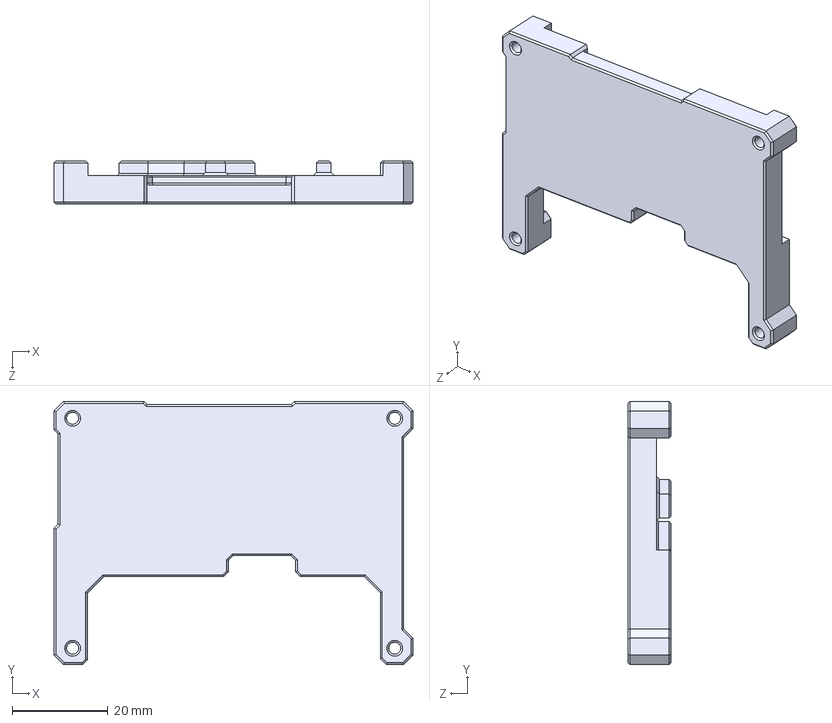
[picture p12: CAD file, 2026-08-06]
3Ds/接收端散热-光-2-Al.STEP
75.0 x 55.0 x 9.00 mm

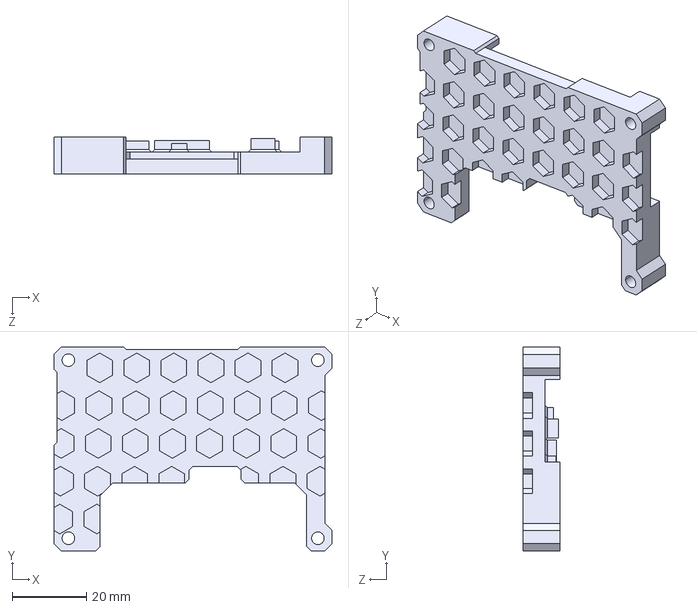
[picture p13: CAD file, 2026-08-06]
3Ds/接收端散热.STEP
75.0 x 55.0 x 10.0 mm

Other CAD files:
3Ds/RXprot_2.gcode.3mf
3Ds/接收端底板.gcode.3mf
3Ds/备份 属于 接收端散热-光-2.SLDPRT
3Ds/接收端底板.STEP
3Ds/接收端散热-半光.STEP
3Ds/RXprot_2_CF.gcode.3mf
3Ds/接收端底板.3mf
3Ds/接收端底板.SLDPRT
3Ds/接收端散热-光-2-Al.SLDPRT
3Ds/接收端散热-光-2.SLDPRT
3Ds/接收端散热-光.SLDPRT
3Ds/接收端散热-半光.SLDPRT
3Ds/接收端散热.SLDPRT

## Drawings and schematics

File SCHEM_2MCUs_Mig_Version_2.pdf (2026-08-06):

# 半桥驱动

# MCU

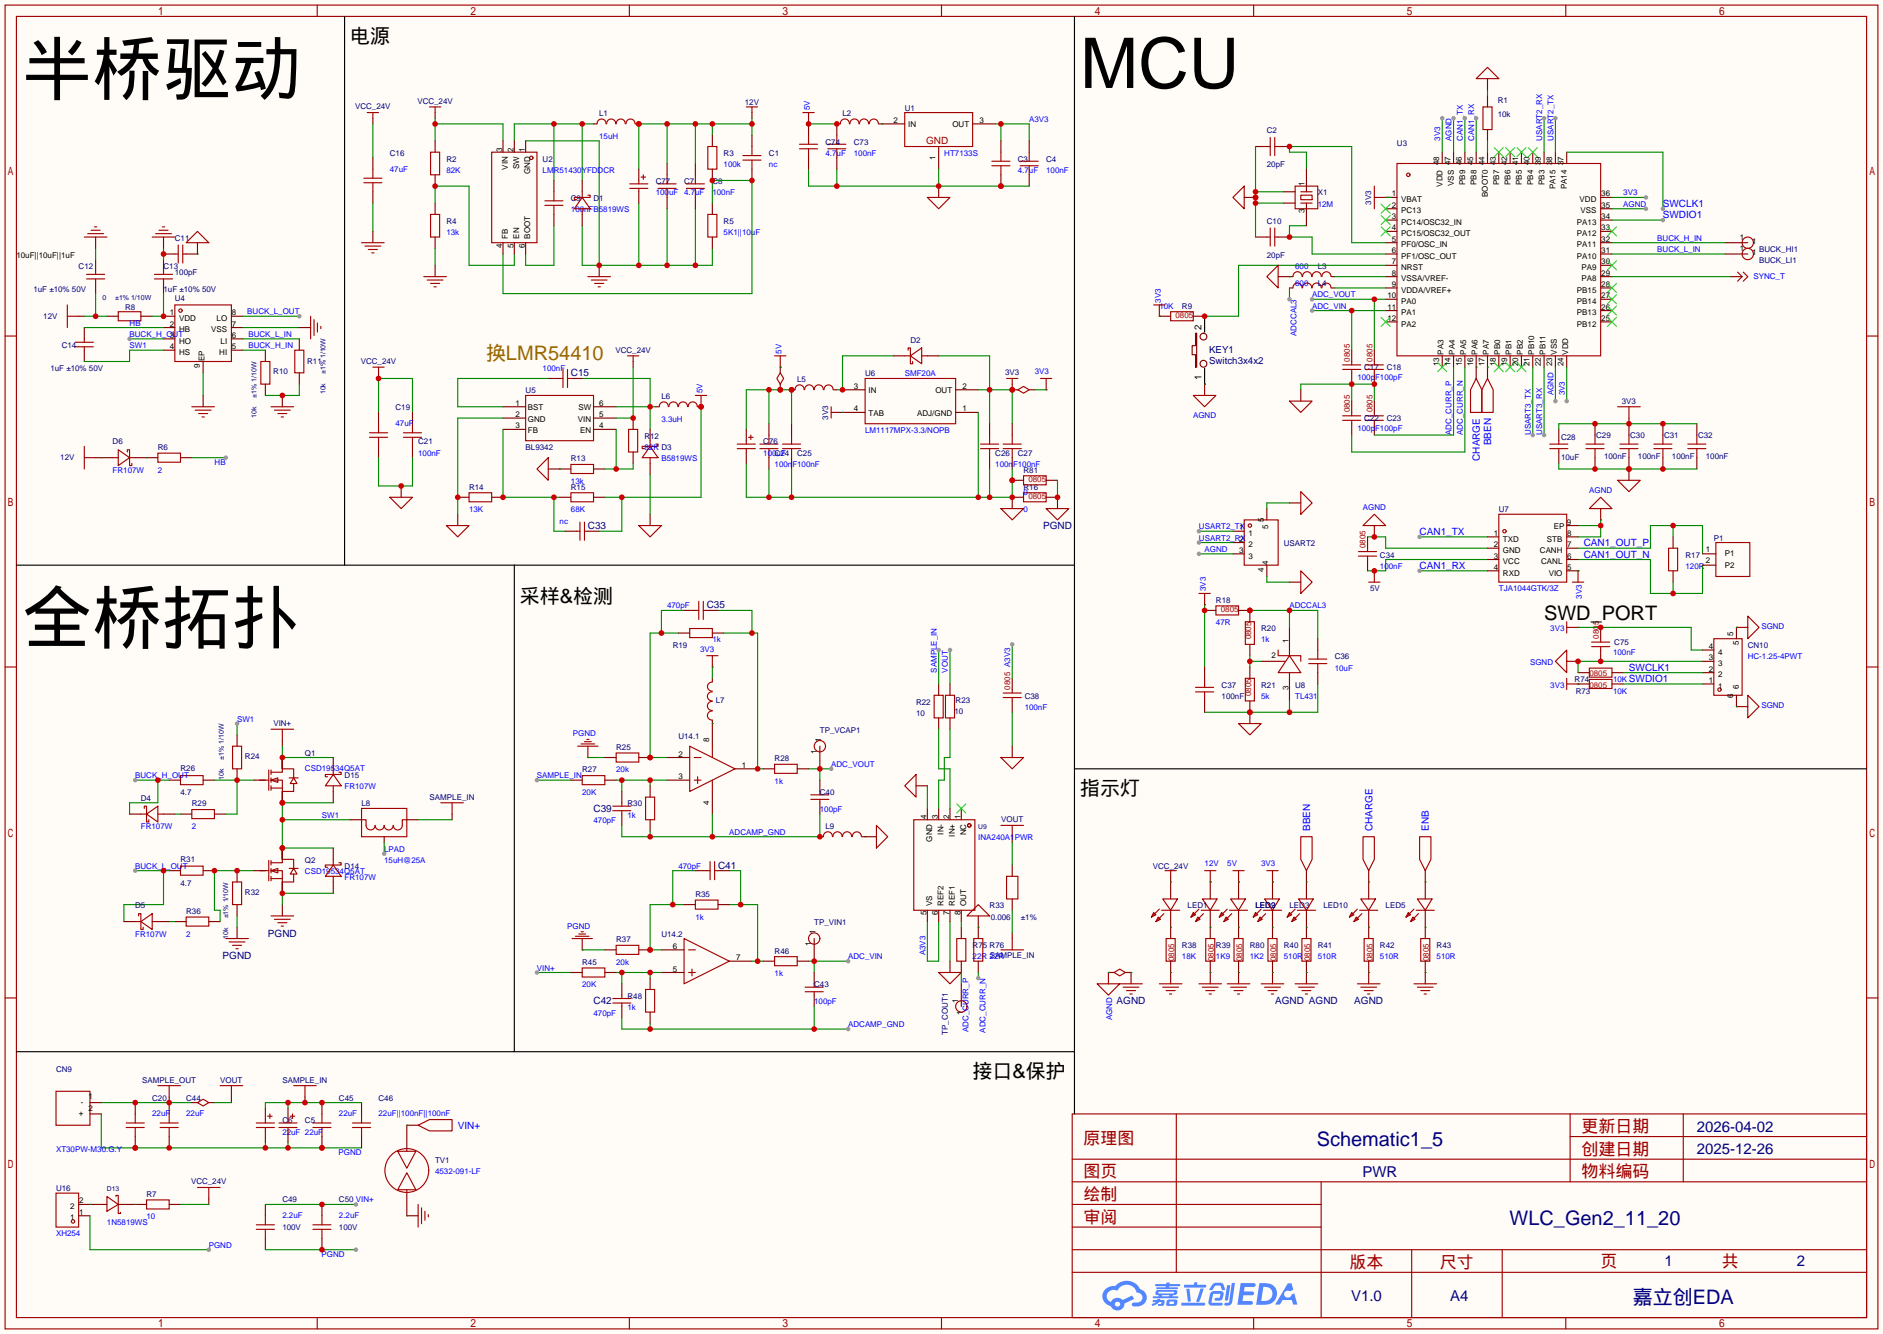
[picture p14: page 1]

# SWD_PORT

# MCU

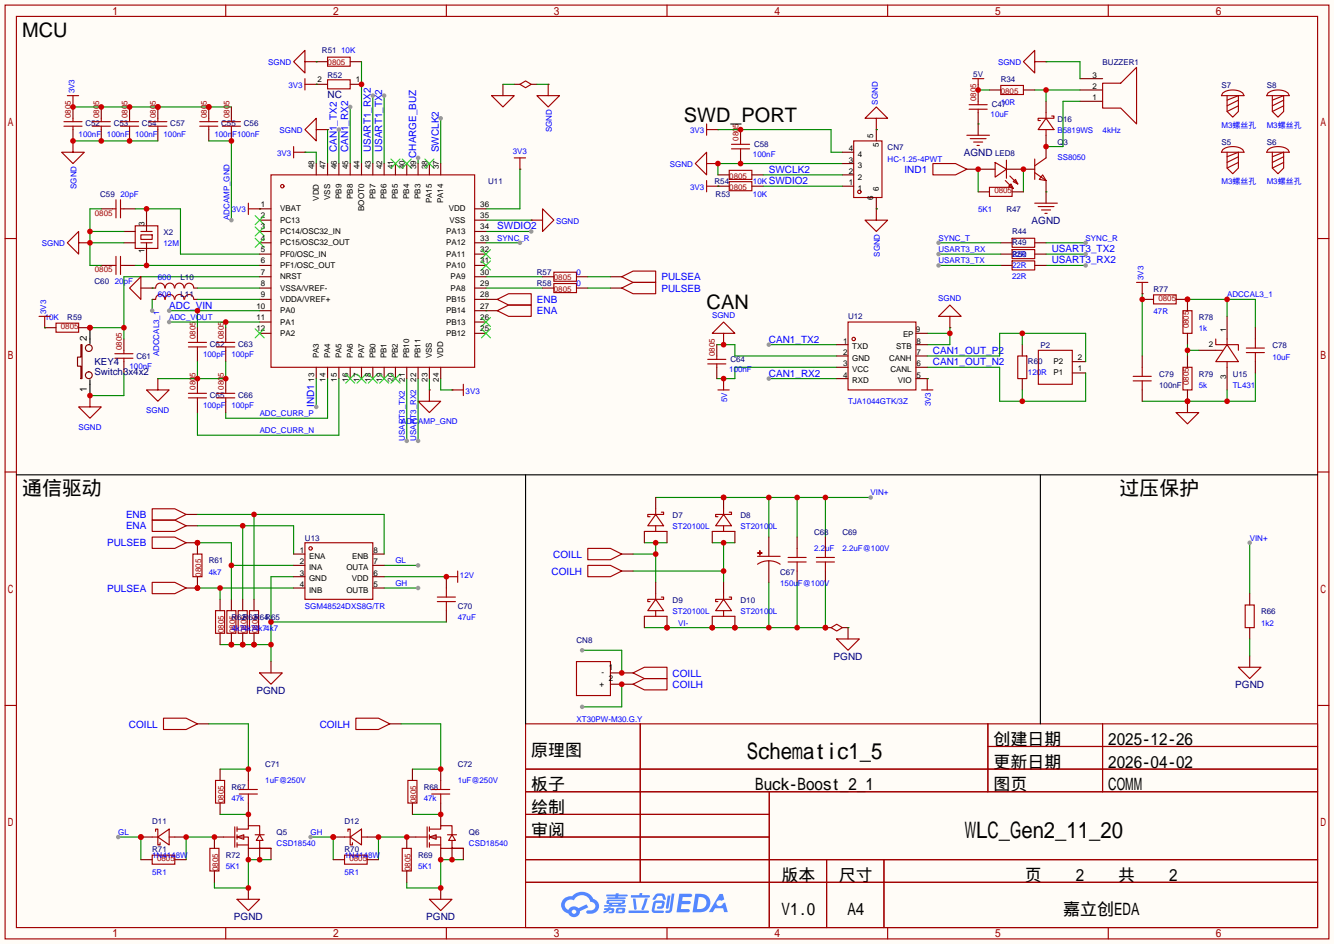
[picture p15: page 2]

原理图 | Schematic1_5 | 创建日期 | 2025-12-26

更新日期 | 2026-04-02

V1.0 | A4 | 嘉立创EDA

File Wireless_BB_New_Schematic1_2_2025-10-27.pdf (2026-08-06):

# 半桥驱动

# MCU

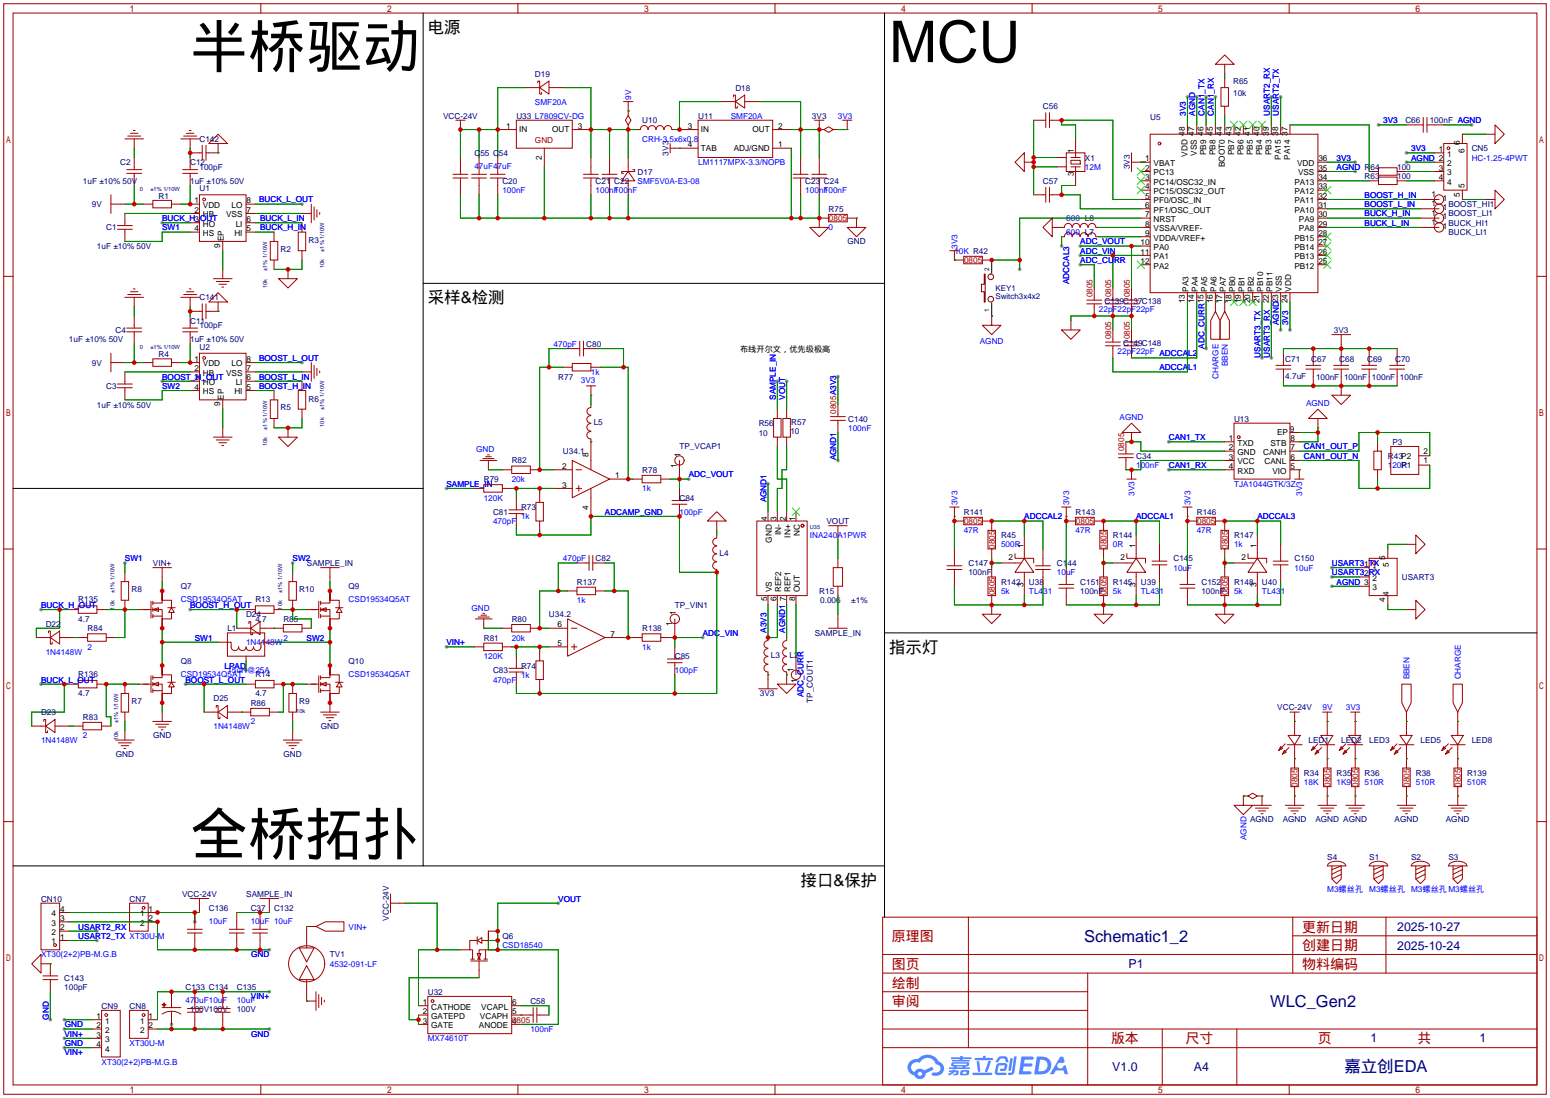
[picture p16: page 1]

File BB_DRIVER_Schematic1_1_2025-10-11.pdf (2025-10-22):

# 半桥驱动

# MCU

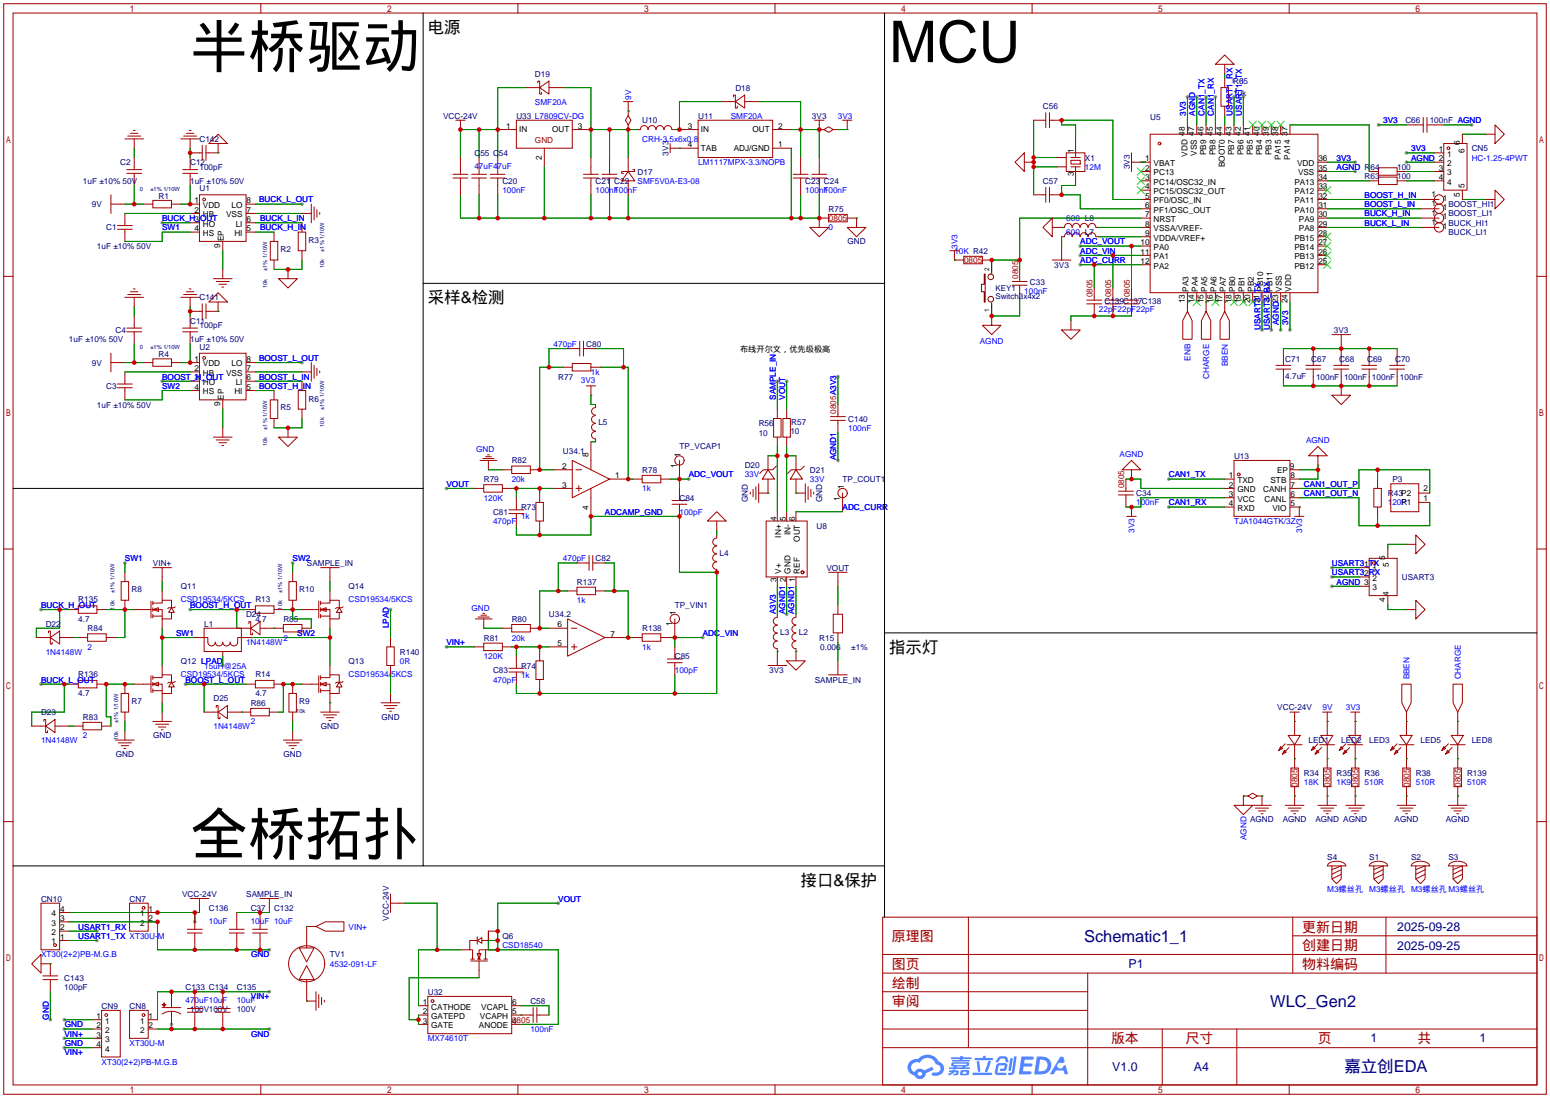
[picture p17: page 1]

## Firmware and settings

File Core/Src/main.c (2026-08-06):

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
/* Includes ------------------------------------------------------------------*/
#include "main.h"
#include "adc.h"
#include "dma.h"
#include "hrtim.h"
#include "tim.h"
#include "usart.h"
#include "gpio.h"

/* USER CODE BEGIN Includes */
#include "bsp_adc.h"
#include "bsp_dwt.h"
#include "bsp_uart.h"
#include "bb_control.h"
#include "board_id.h"
#include "detect_task.h"
/* USER CODE END Includes */


/* USER CODE BEGIN PV */
GPIO_PinState switch_on_off;
/* USER CODE END PV */

void SystemClock_Config(void);
/**
  * @brief  The application entry point.
  * @retval int
  */
int main(void)
{

  /* MCU Configuration--------------------------------------------------------*/

  /* Reset of all peripherals, Initializes the Flash interface and the Systick. */
  HAL_Init();

  /* Configure the system clock */
  SystemClock_Config();

  /* Initialize all configured peripherals */
  MX_GPIO_Init();
  MX_DMA_Init();
  MX_ADC1_Init();
  MX_HRTIM1_Init();
  MX_TIM2_Init();
  MX_ADC2_Init();
  MX_USART3_UART_Init();
  /* USER CODE BEGIN 2 */

  IDCard = BoardID_Detect();
  while (!BoardID_IsValid(IDCard)) {}

  HRTIM1->sMasterRegs.MCMP1R = Hrtim_Period;
  HRTIM1->sMasterRegs.MCMP2R = 0;
  DWT_Init(72);
  DWT_Delay(1.25);

  BB_Control_Init();
  Detect_Init();
  Bsp_UART_Init();
  HAL_TIM_Base_Start_IT(&htim2);
  Bsp_ADC_Init();
  // HAL_TIM_Base_Start_IT(&htim15);

  /* USER CODE END 2 */

  /* Infinite loop */
  /* USER CODE BEGIN WHILE */
  while (1)
  {
    // switch_on_off = HAL_GPIO_ReadPin(GPIOB,GPIO_PIN_10);
    // HAL_GPIO_WritePin(GPIOA,GPIO_PIN_7,switch_on_off);

    /* USER CODE END WHILE */

    /* USER CODE BEGIN 3 */
    //HAL_Delay(1);
  }
  /* USER CODE END 3 */
}

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
/**
  * @brief  Period elapsed callback in non blocking mode
  * @note   This function is called  when TIM17 interrupt took place, inside
  * HAL_TIM_IRQHandler(). It makes a direct call to HAL_IncTick() to increment
  * a global variable "uwTick" used as application time base.
  * @param  htim : TIM handle
  * @retval None
  */
void HAL_TIM_PeriodElapsedCallback(TIM_HandleTypeDef *htim)
{
  /* USER CODE BEGIN Callback 0 */
  static uint32_t count = 0;
  // 10kHz
  if (htim->Instance == TIM2)
  {
      count++;
      Bsp_ADC_ProcessSample();
      Buck_Boost_Task();
      if (count >= 10)
      {
          Detect_Task();
          count = 0;
      }
  }
  /* USER CODE END Callback 0 */
  if (htim->Instance == TIM17) {
    HAL_IncTick();
  }
}

/**
  * @brief  This function is executed in case of error occurrence.
  * @retval None
  */
void Error_Handler(void)
{
  /* USER CODE BEGIN Error_Handler_Debug */
  /* User can add his own implementation to report the HAL error return state */
  __disable_irq();
  while (1)
  {
  }
  /* USER CODE END Error_Handler_Debug */
}

#ifdef  USE_FULL_ASSERT
/**
  * @brief  Reports the name of the source file and the source line number
  *         where the assert_param error has occurred.
  * @param  file: pointer to the source file name
  * @param  line: assert_param error line source number
  * @retval None
  */
void assert_failed(uint8_t *file, uint32_t line)
{
  /* USER CODE BEGIN 6 */
  /* User can add his own implementation to report the file name and line number,
     ex: printf("Wrong parameters value: file %s on line %d\r\n", file, line) */
  /* USER CODE END 6 */
}
#endif /* USE_FULL_ASSERT */

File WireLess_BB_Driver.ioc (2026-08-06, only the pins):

Mcu.UserName=STM32F334C8Tx
PA0.GPIO_Label=ADC1_VOUT
PA0.Signal=ADC1_IN1
PA1.GPIO_Label=ADC1_VIN
PA1.Signal=ADC1_IN2
PA10.GPIO_Label=BUCK_L_IN
PA10.Signal=HRTIM1_CHB1
PA11.GPIO_Label=BUCK_H_IN
PA11.Signal=HRTIM1_CHB2
PA13.Signal=SYS_JTMS-SWDIO
PA14.Signal=SYS_JTCK-SWCLK
PA4.GPIO_Label=ADC_CURR_P
PA4.Signal=ADC2_IN1
PA5.GPIO_Label=ADC_CURR_N
PA5.Signal=ADC2_IN2
PA6.GPIO_Label=VCC_Indicator
PA6.Signal=GPIO_Output
PA7.GPIO_Label=BBEN_Indicator
PA7.Signal=GPIO_Output
PA8.GPIO_Label=SYNC_T
PA8.Signal=HRTIM1_CHA1
PB10.Signal=USART3_TX
PB11.Signal=USART3_RX

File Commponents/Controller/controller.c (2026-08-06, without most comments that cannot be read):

/**
  ******************************************************************************
  * @file    controller.c
  * @author  Wang Hongxi
  * @author  Zhang Hongyu (fuzzy pid)
  * @version V1.1.3
  * @date    2021/7/3
  * @brief   DWT??????????????????? OLS?????????????
  ******************************************************************************
  * @attention 
  *
  ******************************************************************************
  */
#include "controller.h"

/******************************** FUZZY PID **********************************/
//static float FuzzyRuleKpRAW[7][7] = {
//    PB, PB, PM, PM, PS, ZE, ZE,
//    PB, PB, PM, PS, PS, ZE, PS,
//    PM, PM, PM, PS, ZE, PS, PS,
//    PM, PM, PS, ZE, PS, PM, PM,
//    PS, PS, ZE, PS, PS, PM, PM,
//    PS, ZE, PS, PM, PM, PM, PB,
//    ZE, ZE, PM, PM, PM, PB, PB};

static float FuzzyRuleKpRAW[7][7] = {
    {NB, NB, PM, PM, PS, ZE, ZE},
    {NB, NB, PM, PS, PS, ZE, PS},
    {NM, NM, PM, PS, ZE, PS, PS},
    {NM, NM, PS, ZE, PS, PM, PM},
    {NS, NS, ZE, PS, PS, PM, PM},
    {NS, ZE, PS, PM, PM, PM, PB},
    {ZE, ZE, PM, PM, PM, PB, PB}};

static float FuzzyRuleKiRAW[7][7] = {
    {PB, PB, PM, PM, PS, ZE, ZE},
    {PB, PB, PM, PS, PS, ZE, ZE},
    {PB, PM, PM, PS, ZE, PS, PS},
    {PM, PM, PS, ZE, PS, PM, PM},
    {PS, PS, ZE, PS, PS, PM, PB},
    {ZE, ZE, PS, PS, PM, PB, PB},
    {ZE, ZE, PS, PM, PM, PB, PB}};

static float FuzzyRuleKdRAW[7][7] = {
    {PS, PS, PB, PB, PB, PM, PS},
    {PS, PS, PB, PM, PM, PS, ZE},
    {ZE, PS, PM, PM, PS, PS, ZE},
    {ZE, PS, PS, PS, PS, PS, ZE},
    {ZE, ZE, ZE, ZE, ZE, ZE, ZE},
    {PB, PS, PS, PS, PS, PS, PB},
    {PB, PM, PM, PM, PS, PS, PB}};

void Fuzzy_Rule_Init(FuzzyRule_t *fuzzyRule, float (*fuzzyRuleKp)[7], float (*fuzzyRuleKi)[7], float (*fuzzyRuleKd)[7],
                     float kpRatio, float kiRatio, float kdRatio,
                     float eStep, float ecStep)
{
    if (fuzzyRuleKp == NULL)
        fuzzyRule->FuzzyRuleKp = FuzzyRuleKpRAW;
    else
        fuzzyRule->FuzzyRuleKp = fuzzyRuleKp;
    if (fuzzyRuleKi == NULL)
        fuzzyRule->FuzzyRuleKi = FuzzyRuleKiRAW;
    else
        fuzzyRule->FuzzyRuleKi = fuzzyRuleKi;
    if (fuzzyRuleKd == NULL)
        fuzzyRule->FuzzyRuleKd = FuzzyRuleKdRAW;
    else
        fuzzyRule->FuzzyRuleKd = fuzzyRuleKd;

    fuzzyRule->KpRatio = kpRatio;
    fuzzyRule->KiRatio = kiRatio;
    fuzzyRule->KdRatio = kdRatio;

    if (eStep < 0.00001f)
        eStep = 1;
    if (ecStep < 0.00001f)
        ecStep = 1;
    fuzzyRule->eStep = eStep;
    fuzzyRule->ecStep = ecStep;
}
void Fuzzy_Rule_Implementation(FuzzyRule_t *fuzzyRule, float measure, float ref)
{
    float eLeftTemp, ecLeftTemp;
    float eRightTemp, ecRightTemp;
    int eLeftIndex, ecLeftIndex;
    int eRightIndex, ecRightIndex;

    fuzzyRule->dt = DWT_GetDeltaT((void *)&fuzzyRule->DWT_CNT);

    fuzzyRule->e = ref - measure;
    fuzzyRule->ec = (fuzzyRule->e - fuzzyRule->eLast) / fuzzyRule->dt; //
    fuzzyRule->eLast = fuzzyRule->e;

    //????????
    eLeftIndex = fuzzyRule->e >= 3 * fuzzyRule->eStep ? 6 : (fuzzyRule->e <= -3 * fuzzyRule->eStep ? 0 : (fuzzyRule->e >= 0 ? ((int)(fuzzyRule->e / fuzzyRule->eStep) + 3) : ((int)(fuzzyRule->e / fuzzyRule->eStep) + 2)));
    eRightIndex = fuzzyRule->e >= 3 * fuzzyRule->eStep ? 6 : (fuzzyRule->e <= -3 * fuzzyRule->eStep ? 0 : (fuzzyRule->e >= 0 ? ((int)(fuzzyRule->e / fuzzyRule->eStep) + 4) : ((int)(fuzzyRule->e / fuzzyRule->eStep) + 3)));
    ecLeftIndex = fuzzyRule->ec >= 3 * fuzzyRule->ecStep ? 6 : (fuzzyRule->ec <= -3 * fuzzyRule->ecStep ? 0 : (fuzzyRule->ec >= 0 ? ((int)(fuzzyRule->ec / fuzzyRule->ecStep) + 3) : ((int)(fuzzyRule->ec / fuzzyRule->ecStep) + 2)));
    ecRightIndex = fuzzyRule->ec >= 3 * fuzzyRule->ecStep ? 6 : (fuzzyRule->ec <= -3 * fuzzyRule->ecStep ? 0 : (fuzzyRule->ec >= 0 ? ((int)(fuzzyRule->ec / fuzzyRule->ecStep) + 4) : ((int)(fuzzyRule->ec / fuzzyRule->ecStep) + 3)));
    
//		fuzzyRule->eIntervalCount[eLeftIndex] ++;
//		fuzzyRule->ecIntervalCount[ecLeftIndex] ++;
		
		//??????
    eLeftTemp = fuzzyRule->e >= 3 * fuzzyRule->eStep ? 0 : (fuzzyRule->e <= -3 * fuzzyRule->eStep ? 1 : (eRightIndex - fuzzyRule->e / fuzzyRule->eStep - 3));
    eRightTemp = fuzzyRule->e >= 3 * fuzzyRule->eStep ? 1 : (fuzzyRule->e <= -3 * fuzzyRule->eStep ? 0 : (fuzzyRule->e / fuzzyRule->eStep - eLeftIndex + 3));
    ecLeftTemp = fuzzyRule->ec >= 3 * fuzzyRule->ecStep ? 0 : (fuzzyRule->ec <= -3 * fuzzyRule->ecStep ? 1 : (ecRightIndex - fuzzyRule->ec / fuzzyRule->ecStep - 3));
    ecRightTemp = fuzzyRule->ec >= 3 * fuzzyRule->ecStep ? 1 : (fuzzyRule->ec <= -3 * fuzzyRule->ecStep ? 0 : (fuzzyRule->ec / fuzzyRule->ecStep - ecLeftIndex + 3));

		fuzzyRule->eStatue = eLeftIndex;
		fuzzyRule->ecStatue = ecLeftIndex;
		
		fuzzyRule->KpFuzzyTemp[0] = eLeftTemp * ecLeftTemp * fuzzyRule->FuzzyRuleKp[eLeftIndex][ecLeftIndex];
    fuzzyRule->KpFuzzyTemp[1] = eLeftTemp * ecRightTemp * fuzzyRule->FuzzyRuleKp[eRightIndex][ecLeftIndex];
    fuzzyRule->KpFuzzyTemp[2] = eRightTemp * ecLeftTemp * fuzzyRule->FuzzyRuleKp[eLeftIndex][ecRightIndex];
    fuzzyRule->KpFuzzyTemp[3] = eRightTemp * ecRightTemp * fuzzyRule->FuzzyRuleKp[eRightIndex][ecRightIndex];
		
		fuzzyRule->KpFuzzy = fuzzyRule->KpFuzzyTemp[0] + fuzzyRule->KpFuzzyTemp[1] + fuzzyRule->KpFuzzyTemp[2] + fuzzyRule->KpFuzzyTemp[3];
//		fuzzyRule->KpFuzzy = eLeftTemp * ecLeftTemp * fuzzyRule->FuzzyRuleKp[eLeftIndex][ecLeftIndex] +
//                         eLeftTemp * ecRightTemp * fuzzyRule->FuzzyRuleKp[eLeftIndex][ecRightIndex] +
//                         eRightTemp * ecLeftTemp * fuzzyRule->FuzzyRuleKp[eRightIndex][ecLeftIndex] +
//                         eRightTemp * ecRightTemp * fuzzyRule->FuzzyRuleKp[eRightIndex][ecRightIndex];
		
    fuzzyRule->KpFuzzy *= fuzzyRule->KpRatio;
//		fuzzyRule->KpFuzzy = (fuzzyRule->KpFuzzy + fuzzyRule->LastKpFuzzy) / 2;
//		fuzzyRule->LastKpFuzzy = fuzzyRule->KpFuzzy;

    fuzzyRule->KiFuzzy = eLeftTemp * ecLeftTemp * fuzzyRule->FuzzyRuleKi[eLeftIndex][ecLeftIndex] +
                         eLeftTemp * ecRightTemp * fuzzyRule->FuzzyRuleKi[eRightIndex][ecLeftIndex] +
                         eRightTemp * ecLeftTemp * fuzzyRule->FuzzyRuleKi[eLeftIndex][ecRightIndex] +
                         eRightTemp * ecRightTemp * fuzzyRule->FuzzyRuleKi[eRightIndex][ecRightIndex];
    fuzzyRule->KiFuzzy *= fuzzyRule->KiRatio;

    fuzzyRule->KdFuzzy = eLeftTemp * ecLeftTemp * fuzzyRule->FuzzyRuleKd[eLeftIndex][ecLeftIndex] +
                         eLeftTemp * ecRightTemp * fuzzyRule->FuzzyRuleKd[eRightIndex][ecLeftIndex] +
                         eRightTemp * ecLeftTemp * fuzzyRule->FuzzyRuleKd[eLeftIndex][ecRightIndex] +
                         eRightTemp * ecRightTemp * fuzzyRule->FuzzyRuleKd[eRightIndex][ecRightIndex];
    fuzzyRule->KdFuzzy *= fuzzyRule->KdRatio;
}
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

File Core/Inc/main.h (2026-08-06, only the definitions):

#define L_duty 0.05f
#define deadtime 100
#define H_duty 0.95f
#define Hrtim_Period 23040
#define ADC1_VOUT_Pin GPIO_PIN_0
#define ADC1_VOUT_GPIO_Port GPIOA
#define ADC1_VIN_Pin GPIO_PIN_1
#define ADC1_VIN_GPIO_Port GPIOA
#define ADC_CURR_P_Pin GPIO_PIN_4
#define ADC_CURR_P_GPIO_Port GPIOA
#define ADC_CURR_N_Pin GPIO_PIN_5
#define ADC_CURR_N_GPIO_Port GPIOA
#define VCC_Indicator_Pin GPIO_PIN_6
#define VCC_Indicator_GPIO_Port GPIOA
#define BBEN_Indicator_Pin GPIO_PIN_7
#define BBEN_Indicator_GPIO_Port GPIOA
#define SYNC_T_Pin GPIO_PIN_8
#define SYNC_T_GPIO_Port GPIOA
#define BUCK_L_IN_Pin GPIO_PIN_10
#define BUCK_L_IN_GPIO_Port GPIOA
#define BUCK_H_IN_Pin GPIO_PIN_11
#define BUCK_H_IN_GPIO_Port GPIOA

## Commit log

2025-10-23 10.24电压pid，前馈，比例修正优化
2025-10-25 电流pid参数小改
2025-10-28 (未测试版) 新原理图修改配置文件工程； 增加动态占空比； 去掉PB10控制开关；
2025-10-28 pdf文档
2025-10-29 整合代码
2025-11-05 修复ozone错误
2025-11-10 不用校准版，电流采样通过，双环竞争未通过
2025-11-11 三模式切换改成史密斯，修改电流环和电压环竞争逻辑
2025-11-13 修改build的bug，远程分支删除build存在
2025-12-18 新板子手册
2025-12-20 BB稳定性测试（含Build）
2025-12-21 增加输入欠压过压保护
2025-12-23 串口测试，中断无法进入
2025-12-25 二合一接收板散热片
    [接收端底板.3mf, 接收端底板.SLDPRT, 接收端底板.STEP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]
2025-12-26 能用串口收发
2025-12-26 删除build
2025-12-28 可能有bug没查出来版）
2025-12-28 关闭串口的buck_boost
2025-12-28 新增输入电压异常看门狗保护
2025-12-28 添加状态机流程图
2025-12-28 头文件重定义命名错误）
2025-12-29 修改hrtim寄存器刷新bug
2025-12-29 优化宏定义，修复字符串转换
2025-12-30 111修bug_promax
2025-12-30 30号下午调试，boost模式抽搐
2026-01-02 去Cmake
2026-01-03 更新3D文件
    [接收端底板.SLDPRT, 接收端底板.STEP]
2026-01-04 同意计算电压增益； 占空比计算逻辑； 去掉占空比限幅，改电压增益限幅； 去掉静态占空比限幅，全部本地动态电压增益限幅； 前馈参数加在电压增益上； 修改比较值计算逻辑，统一占空比为上管占空比； 修改死区时间为60ns； 特化Buck-Boost比较值计算，Buck路移相180度； 提高采样一阶滤波器带宽； 增加调试模式（效果不佳）； 考虑buck和boost模式闲置单管导通自举电容充电，短暂导通闲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
2026-01-04 双MCU板子原理图
2026-01-04 缓起测试版
2026-01-05 增加matlab脚本
2026-01-06 1.6下午更改 更改缓启动计算逻辑 更改缓启动计算位置 更改部分变量名 目前DMA搬运ADC数据错误，ADC看门狗配置错误（通道一和通道二似乎一会正一会反）
2026-01-06 实时运行buck计算 修复不能出缓启动问题 目前ADC采样不稳 输出占空比不稳定（过几秒跳变，不定时） 刚进ss时容易输出一个周期的高占空比 修改意见： 使用新的系统时钟和终端触发源，降低触发速率，必要时阉割PID
    [WireLess_BB_Driver.ioc, bb_control.c, bb_control.h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]
2026-01-06 重构bb_control代码逻辑， 修正ADC采样滤波频率， 修改电压输入输出对应内存错误
2026-01-07 修复开机定时器输出异常 修复缓启动开头占空比给满的bug
    [接收端底板.SLDPRT, 接收端散热.SLDPRT]
2026-01-08 修改电压负反馈逻辑，使用三角函数映射误差和电压增益，电压输出稳定 增加电流负反馈，电流负反馈和电压负反馈竞争异常震荡
2026-01-08 增加电压电流切换延时
2026-01-09 恒流Kp动态调节 电流输出增益滤波 修改一阶滤波，消除nan值 电流误差反馈归一化
2026-01-13 修改串口接收（串口调试助手测试过关）， 修改输入电压最大值，电流最大值，
2026-01-14 增加串口接收判断开启输出使能
2026-01-15 增加佛祖保佑， 增加癫疯之作， 增加串口数据修改状态， 修改串口超时判断时间， 增加看门狗设置阈值保护，
2026-01-17 缓启动时间不统一bug
2026-01-17 增加电压过高保护； 将指示灯与引脚输出与状态绑定； 优化占空比修改逻辑
2026-01-21 硬件说明文档
2026-01-21 文档加尺寸参数
2026-03-04 加个文件
2026-03-05 机械和忽略设置
    [接收端底板.3mf, 接收端底板.SLDPRT, 接收端底板.STEP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]
2026-03-06 修改采样触发到TIMB的第二个比较值 几乎无改善
2026-03-09 修改adc采样触发
2026-03-10 改关于硬件的一些参数
2026-03-12 增加芯片ID读取功能，修改零偏等参数定义方式，修复hrtim引脚输出极性错误问题，将ADC采样改成timerA触发
2026-03-13 新版1常量
2026-03-19 修复开启比较值刷新延迟bug 一些3D文件
    [接收端散热-光-b.SLDPRT, 接收端散热-光.SLDPRT, 接收端散热-光.STEP]
2026-04-03 修正版接收原理图 修正版外壳
    [备份 属于 接收端散热-光-2.SLDPRT, 接收端散热-光-2.SLDPRT, 接收端散热-光-2.STEP]
2026-04-05 尝试优化定时器预装载测试1
2026-04-05 Revert "尝试优化定时器预装载测试1"
    This reverts commit c8e88072d9b955435c7fbcb4e0f9d439b10e730a.
    [WireLess_BB_Driver.ioc, bb_control.c, main.c]
2026-04-05 更新ignore
2026-04-05 删除.vscode的追踪
2026-04-14 新mcu，修改引脚，修改adc触发源
2026-04-15 增加timerA作为信号引脚给双MCU的ADC采样；修复初始上电时引脚电压异常bug；增加芯片个数；修改电压输出期望；增加新芯片ADC常量；增加串口发送状态；修复芯片读取异常问题
2026-04-15 修改芯片识别失败处理
2026-04-15 补传debug和ioc
2026-04-15 4-15 3Ds
    [RXprot_2.gcode.3mf, 备份 属于 接收端底板.SLDPRT, 备份 属于 接收端散热-光-2.SLDPRT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]
2026-04-20 3D文件 开关频率提升到133.33k ADC中断触发开启方式 定时器重置结构
    [RXprot_2_CF.gcode.3mf]
2026-04-23 修改滤波器截止频率到8k
2026-05-11 一些3D文件 增加电压驱动的输出灌电流保护功能 整理ID识别并添加了一块新板 将使能和失能对应到定时器输出，串口刷新完全覆盖使能控制，灌电流，串口超时，串口失能都将禁用定时器输出（不影响ADC触发）
    [RXprot_2.gcode.3mf, 备份 属于 接收端底板.SLDPRT, 备份 属于 接收端散热-光-2-Al.SLDPRT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]
2026-05-12 编译器优化升级到o2，修复部分bug，无明显错误
2026-05-13 十倍采样频率，批处理一阶滤波 取消ADC中断，改在PID计算前处理数据 AI优化分支
2026-05-23 保护壳3D 新板子标定 修改灌流保护阈值
2026-05-27 26区域赛预检录固件
2026-06-04 删除未用着的库
2026-06-04 RMUC结束版本与传承文档的初步编写
2026-06-10 传Readme

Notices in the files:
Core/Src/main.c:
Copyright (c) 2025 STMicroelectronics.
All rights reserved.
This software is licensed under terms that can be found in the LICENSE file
